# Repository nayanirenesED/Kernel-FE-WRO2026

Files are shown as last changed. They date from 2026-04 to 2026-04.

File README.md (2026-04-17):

# 🤖 KERNEL — WRO Future Engineers 2026

<p align="center">
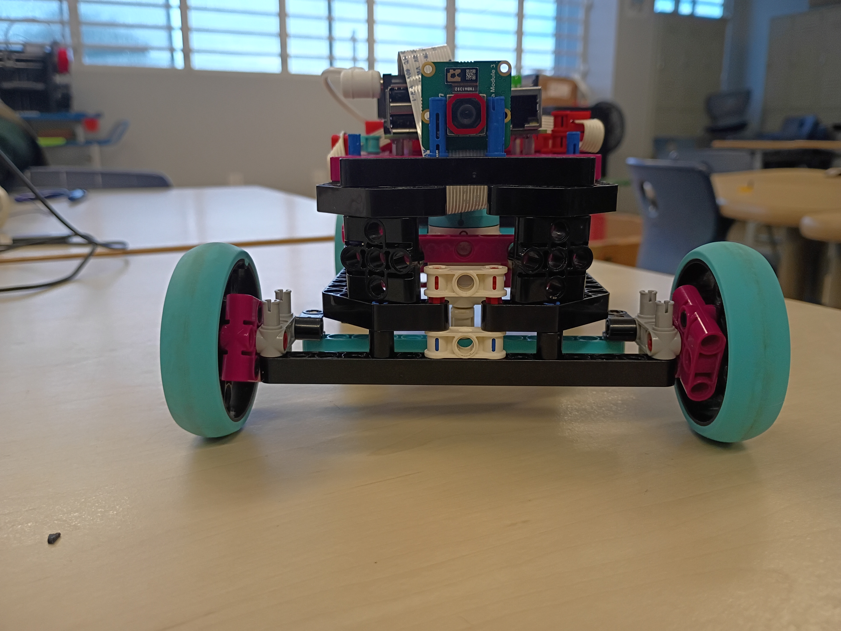
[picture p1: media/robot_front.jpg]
KERNEL Robot
  
</p>

> **World Robot Olympiad 2026 – Future Engineers**  
> Self-Driving Cars Challenge | Barceloneta, Puerto Rico 🇵🇷

---

## 👥 The Team

| Name | Role |
|---|---|
| Nayán G. Irenes Torres | Software Development |
| Yatziel O. Rivera Álvarez | Mechanical Design |
| Jesús Montoyo Heredia | Electronics & Sensors |
| Yanrick G. Irenes Torres | Media & Documentation |

**Coach:** Carlos Olivera  
**Location:** Barceloneta, Puerto Rico  
**Category:** WRO Future Engineers 2026 (Ages 14–22)

---

## 📋 Table of Contents

1. [What the Challenge Is About](#what-the-challenge-is-about)
2. [How We Think About It](#how-we-think-about-it)
3. [How the Robot Evolved](#how-the-robot-evolved)
4. [How the Robot Is Built (V2)](#how-the-robot-is-built-v2)
5. [Power System](#power-system)
6. [Sensors](#sensors)
7. [How the Software Works](#how-the-software-works)
8. [Decisions We Made and Why](#decisions-we-made-and-why)
9. [Repository Structure](#repository-structure)
10. [How to Reproduce Our Robot](#how-to-reproduce-our-robot)

---

## 🏁 What the Challenge Is About

The WRO Future Engineers 2026 challenge requires teams to build a fully autonomous vehicle that moves completely on its own, with no one controlling it. There are two rounds:

**Round 1:** The robot has to complete 3 full laps around a square track. At each corner, the robot has to decide whether to turn right or left on its own, without knowing in advance which direction it'll be running that round.

**Round 2:** Same as Round 1, but now there are obstacles on the track. Green obstacles have to be avoided on the left, red ones on the right. At the end, the robot has to reverse-park inside a zone marked in magenta.

The hardest part is that the track changes every round, and the robot never knows exactly what it'll find. It has to make its own decisions.

---

## 💡 How We Think About It

From the start, we asked ourselves: what's better, **a complicated robot or a robot that always works?**

We chose the second one. **Simple = Reliable.**

A robot with a lot of parts has a lot of things that can break. Code that's hard to read is hard to fix the night before a competition. We applied this thinking to every decision we made; fewer mechanical parts, modular code, well-placed sensors, and testing often to catch problems early.

---

## 🔄 How the Robot Evolved

We didn't get to V2 in a straight line. The robot went through a real evolution driven by what we learned at the first regional competition.

### Robot V1 — LEGO Only

Our first version used only LEGO SPIKE Prime components:

- SPIKE Prime Hub (main controller)
- Large Motor (traction)
- Medium Motor (steering)
- Color Sensor (floor line detection)
- **Official SPIKE Prime rechargeable battery** (plugs directly into the hub)

No Raspberry Pi, no camera, no external sensors. Simple, self-contained, and powered entirely by the LEGO hub battery.

The color sensor was the bottleneck. It needed to be very close to the floor to read reliably, so close that by the time it detected a line, the robot was almost past it. And without a camera, we had no way to detect obstacles at all.

### February 21, 2026 — First Regional Competition

We competed in the first regional with V1. We couldn't get consistent lap completions; the sensor limitations were obvious on the real track. But competing was worth it. We saw the actual track, the lighting, and what we were really up against.

After the regional, we made the call: rebuild.

### Robot V2 — The Hybrid (Current)

We kept what worked and replaced what didn't:

| | V1 | V2 |
|--|----|----|
| Controller | SPIKE Prime Hub | Raspberry Pi 4B + Build HAT |
| Line detection | SPIKE Color Sensor | Arducam IMX708 12MP camera |
| Distance sensing | None | 3× VL53L0X ToF sensors |
| Orientation | None | BNO08X IMU |
| Traction motor | LEGO Large ✅ kept | LEGO Large ✅ |
| Steering motor | LEGO Medium ✅ kept | LEGO Medium ✅ |
| Wheels | LEGO | LEGO (custom 3D-printed in progress) |
| **Power** | **SPIKE hub battery** | **18650 Li-ion cells + LX-2BUPS module** |

The motors stayed — they're precise and reliable. Everything else changed.

**The power problem** was one of the hardest challenges in the transition. V1 ran off the LEGO hub's built-in rechargeable battery. Plug it in, and it works. V2 is a completely different story. The Raspberry Pi and Build HAT need an external power source, and the Build HAT specifically requires 8–12V through a barrel jack.

Finding the right battery setup took a lot of time and research. This was one of the main reasons we couldn't participate in the second regional on March 28th; we hadn't fully validated the power system in time.

### March 28, 2026 — Second Regional

We weren't able to participate. Between the power system not being fully validated and the overall state of V2 at that point, we made the call to sit this one out and keep building.

---

## ⚙️ How the Robot Is Built (V2)

### The Chassis

Built on LEGO Technic pieces, lets us adjust quickly without special tools. Approximately **250 × 150 × 110 mm**, around **600 grams**, within WRO's size limits.

**Rear-wheel drive:** two driven wheels in the back, free-spinning wheels in front. Simple and light.

### The Motors

| Motor | Port | What It Does |
|---|---|---|
| SPIKE Prime Large Motor | Port A (Build HAT) | Moves the robot forward |
| SPIKE Prime Medium Motor | Port B (Build HAT) | Controls steering |

The steering motor uses absolute position control: 0° straight, +90° right, -90° left. Much more precise than time-based control, which varies with battery voltage.

### Physical Buttons

The robot has two physical buttons for competition use:

| Button | Color | Function |
|---|---|---|
| Power | 🔴 Red | Cuts power between LX-2BUPS and Build HAT |
| Run | 🟢 Green | Starts `kernel_robot_r1.py` via GPIO 17 |

The green button connects to **GPIO 17 (Pin 11)** and **GND (Pin 9)** on the Raspberry Pi. 
When pressed, it triggers `boton_inicio.py`, which launches the main robot program automatically.

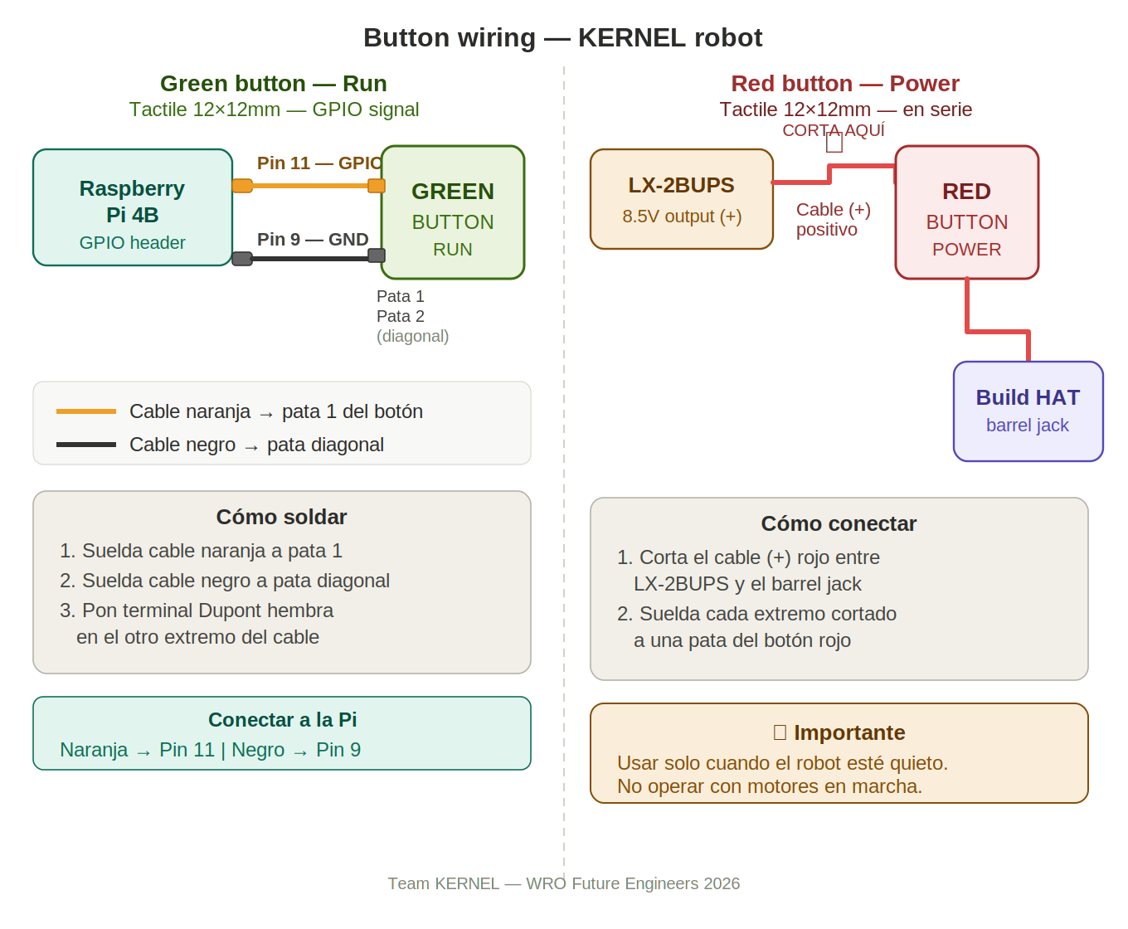
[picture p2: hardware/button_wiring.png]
Button wiring


### The Wheels

V2 currently runs on standard LEGO wheels. The custom wheel design is in progress:

- **Rim:** PLA/PETG, ~65mm diameter, 22mm wide, designed in CAD from scratch using Fusion 360
- **Tire:** TPU (or similar flexible filament) for better grip on the competition surface

<p align="center">
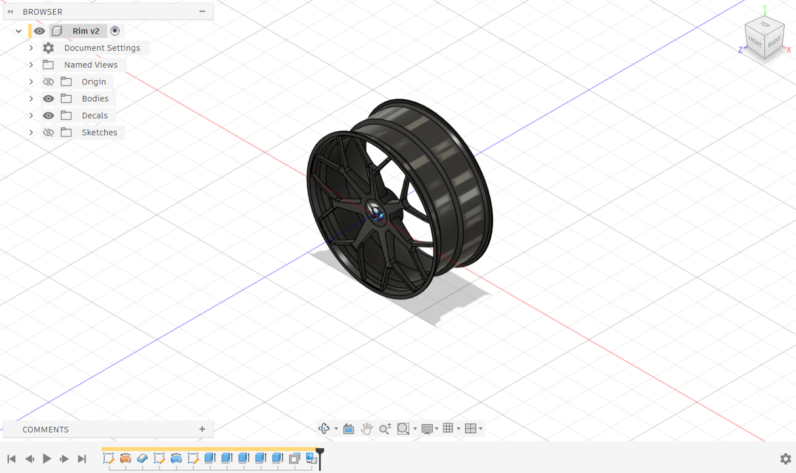
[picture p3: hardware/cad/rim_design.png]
Rim CAD design in Fusion 360
  
</p>

---

## 🔋 Power System

This was one of the biggest engineering challenges of the whole project.

### V1 Power: Simple

V1 used the **official SPIKE Prime rechargeable battery** that plugs directly into the hub. No external wiring, no voltage management, nothing to figure out. Just charge it and go.

### V2 Power: A Whole Different Problem

V2 needs to power two things simultaneously:
- The **Raspberry Pi 4B** needs stable 5V
- The **Build HAT** needs 8–12V through a barrel jack

After researching options and testing different setups, our solution is **two 18650 lithium cells** connected to an **LX-2BUPS boost module**. This module outputs a stable 8.5V to the Build HAT barrel jack. The Build HAT then passes power to the Raspberry Pi through its GPIO pins — one battery source for the entire robot.

| Component | Voltage | Approximate Current |
|---|---|---|
| Raspberry Pi 4B | 5V | ~1.5–2.5A |
| Build HAT + motors | 8.5V | up to 3A under load |
| IMX708 Camera | 3.3V | ~0.25A |
| 3× ToF sensors | 3.3V | ~0.06A total |
| BNO08X IMU | 3.3V | ~0.01A |

### The Battery Case

To keep the power system secure on the robot, we designed and printed a custom case that holds the LX-2BUPS module and the two 18650 cells together in one unit. Having the power system loose wasn't an option for competition.

<p align="center">
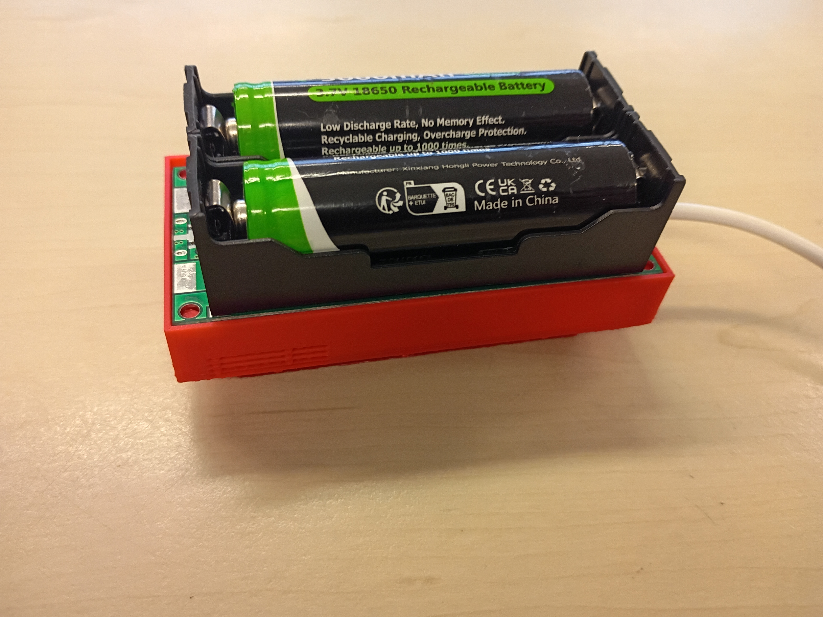
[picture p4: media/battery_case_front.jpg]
Custom battery case
  
</p>

### What We Know and What We're Still Testing

The 18650 cells have been tested, and the system works. One thing we're still validating is full endurance, how the cells perform through a complete competition run under full motor load. The cells must stay above 3.5V under load, or the Build HAT can reset. We'll find out definitively at the next regional.

We test the batteries before every session.

---

## 📡 Sensors

### Competition Setup (April 2026 Regional)

For this regional we made a deliberate decision: **run on camera only.** The Arducam IMX708 gives us everything we need to complete both rounds — line colors, obstacle colors, position, and distance. Fewer components means fewer things that can fail on competition day.

**Arducam IMX708 (12MP)** — the main and only active sensor. Connected via CSI cable, aimed forward and slightly down. Detects:
- Orange and blue floor lines → turn direction
- Red and green obstacles → bypass direction
- Position: left, center, right
- Distance: far, medium, close, very close

### Acquired and Tested (Future Integration)

We acquired, wired, and tested the following sensors on the bench. They work and will be integrated in a future version:

```
Raspberry Pi 4B
       │
  TCA9548A (I2C multiplexer)
  ├── Channel 0: VL53L0X ToF — Front
  ├── Channel 1: VL53L0X ToF — Left
  ├── Channel 2: VL53L0X ToF — Right
  └── Channel 3: BNO08X IMU
```

We confirmed that both the multiplexer (0x70) and IMU (0x4b) are detected on the I2C bus, and the IMU outputs quaternion data correctly.

| Sensor | Status | Purpose |
|---|---|---|
| IMX708 12MP camera | ✅ Active | Line detection, obstacle detection, navigation |
| VL53L0X ×3 | 🔜 Future | Precise distance to obstacles and walls |
| BNO08X IMU | 🔜 Future | Heading correction and orientation |
| SPIKE Color Sensor | V1 only | Used in V1, not present in V2 |

### Wiring Diagram

<p align="center">
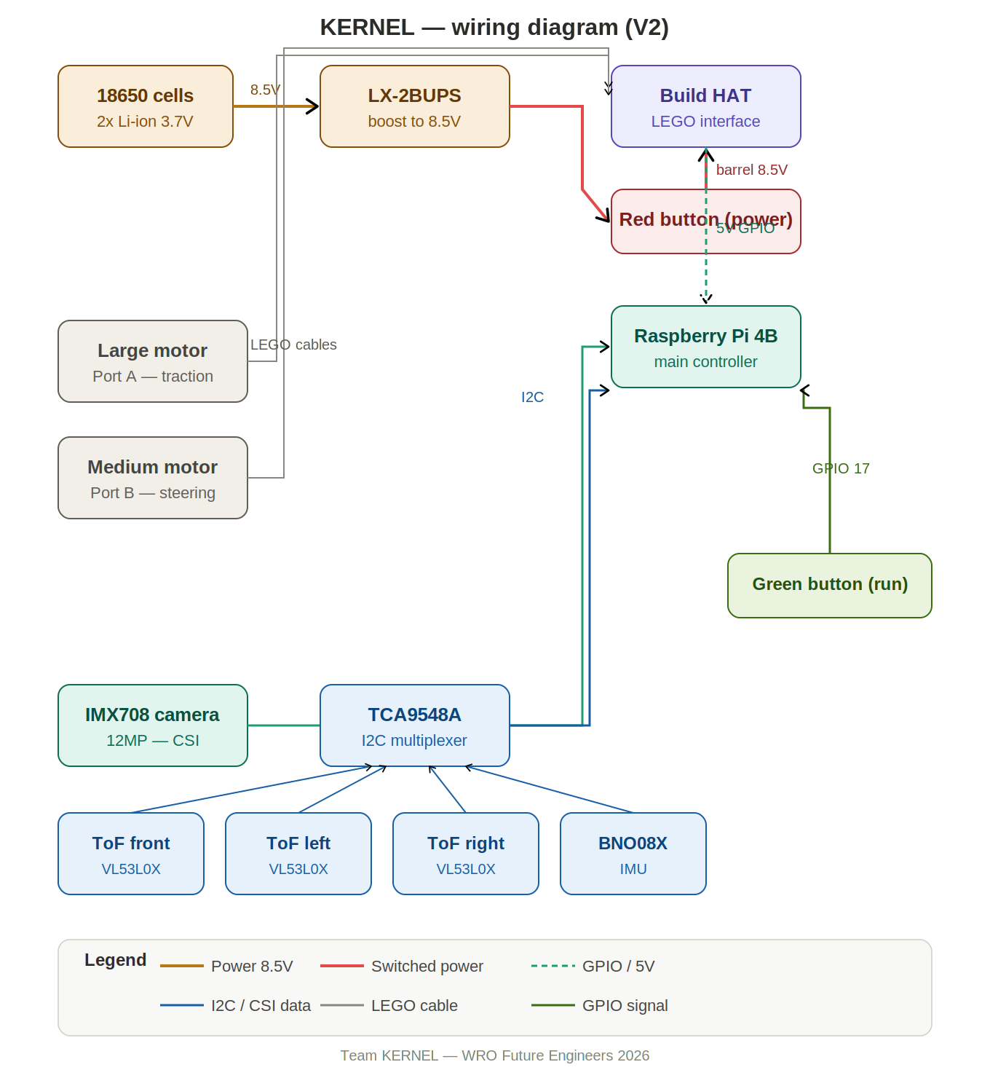
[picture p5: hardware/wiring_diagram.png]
Wiring Diagram
  
</p>

---

## 💻 How the Software Works

### One Program, Both Rounds

```
┌─────────────────────────────────────────────────────┐
│                  Raspberry Pi 4B                    │
│                                                     │
│  ┌─────────────────┐   JSON data    ┌─────────────┐ │
│  │  wro_camera.py  │ ─────────────▶ │kernel_robot │ │
│  │   (the "eyes")  │                │  _r1.py     │ │
│  │   Port 5000     │ ◀───────────── │(the "brain")│ │
│  └─────────────────┘                └─────────────┘ │
│         │                                 │         │
│    IMX708 Camera                     Build HAT       │
│                                      Motors A & B    │
└─────────────────────────────────────────────────────┘
```

- **`wro_camera.py`** — processes camera frames, detects colors, publishes JSON results on port 5000. Viewable live in any browser.
- **`kernel_robot_r1.py`** — handles **both Round 1 and Round 2** in a single program. Reads camera data every 50ms, decides what to do, and moves the motors. Round 1 logic (line following) and Round 2 logic (obstacle avoidance) are both in here.

### How It Decides at Each Corner

```
        Starts
           │
           ▼
    ┌─────────────┐
    │   Moving    │ ◀──────────────────────────┐
    │   forward   │                            │
    └──────┬──────┘                            │
           │                                   │
    Sees a colored line?                       │
           │                                   │
      ┌────┴────┐                              │
      ▼         ▼                              │
   Orange      Blue                            │
   → Turn      → Turn                          │
    right       left                           │
      └────┬────┘                              │
           ▼                                   │
    Wait 3 seconds ─────────────────────────── ┘
           │
    Reached 12 corners?
           │
           ▼
        Stop ✅  (3 laps done)
```

4 corners = 1 lap. 12 corners = 3 laps. The 3-second wait after each turn prevents the same line from being counted twice (entering and exiting the turn).

### Color Detection

HSV detection — more stable than RGB under changing lighting.

| Element | H Range | S Range | V Range |
|---|---|---|---|
| Orange line 🟠 | 8–22 | 150–255 | 100–255 |
| Blue line 🔵 | 100–130 | 150–255 | 50–255 |
| Red obstacle 🔴 | 0–10 / 170–179 | 150–255 | 80–255 |
| Green obstacle 🟢 | 45–80 | 150–255 | 50–255 |
| Parking zone 🟣 | 140–170 | 150–255 | 50–255 |

**Zone filter:** Detection of orange and blue is restricted to the bottom half of the frame. The cardboard walls that we used while testing are the same colors as the floor lines. Without this filter, the robot turned randomly every time it saw a wall.

### Code Structure

```
src/
├── kernel_robot_r1.py     # Main program
├── wro_camera.py          # Vision server
├── calibrar_colores.py    # Color calibration tool
├── sensors/
│   ├── tof.py
│   └── imu.py
└── actuators/
    └── motors.py
```

Camera server starts automatically on boot via systemd — no keyboard or screen needed.

---

## 🧠 Decisions We Made and Why

### Problems We Solved

| Problem | What Caused It | How We Fixed It |
|---|---|---|
| Motors didn't respond | `console=serial0,115200` in `cmdline.txt` blocked the serial port | Deleted that line |
| Camera didn't show up | CSI cable inserted backwards | Physical check every time we open the robot |
| Random turns in straight sections | Colored walls triggered line detector | Zone filter: bottom half of frame only |
| Counted corners twice | Same line detected entering and exiting | 3-second blocking window after every turn |
| Never detected anything | JSON key names didn't match between programs | Synced all names exactly |
| Couldn't find the right battery for V2 | Build HAT needs 8–12V barrel jack, no simple off-the-shelf solution | 18650 cells + LX-2BUPS module + custom printed case |

### Risks We're Managing

| Risk | How Likely | How Bad | How We Handle It |
|---|---|---|---|
| 18650 cells drop under full load | Medium | High — robot resets | Test before every session, spare cells ready |
| HSV ranges off at competition venue | Medium | High — robot can't navigate | `calibrar_colores.py` ready for on-site recalibration |
| Turn angle needs adjustment | Medium | Medium | Single variable `ANGULO_GIRO`, easy to tune |
| Camera cable disconnects | Low | High | Physically secured; systemd detects failure |

---

## 📁 Repository Structure

```
Kernel-FE-WRO2026/
├── README.md
├── LICENSE
├── .gitignore
├── src/
│   ├── kernel_robot_r1.py
│   ├── wro_camera.py
│   └── calibrar_colores.py
├── hardware/
│   ├── wiring_diagram.png
│   └── cad/
│       ├── rim.stl
│       └── battery_case.stl
├── docs/
│   └── engineering_journal.md
└── media/
    ├── robot_front.jpg
    ├── robot_rear.jpg
    ├── robot_side_left.jpg
    ├── robot_side_right.jpg
    ├── robot_top.jpg
    ├── robot_bottom.jpg
    ├── robot_v1_top.jpg
    ├── robot_v1_front.jpg
    ├── robot_v1_rear.jpg
    ├── robot_v1_left.jpg
    ├── robot_v1_right.jpg
    ├── robot_v1_bottom.jpg
    ├── battery_case_front.jpg
    ├── battery_case_side.jpg
    ├── battery_case_back.jpg
    ├── battery_case_usbc.jpg
    ├── battery_case_interior.jpg
    ├── test_color_detection.jpg
    ├── test_multiplexer_imu.jpg
    ├── test_i2cdetect.jpg
    ├── test_imu_output.jpg
    ├── test_network_config.jpg
    ├── test_bug_lap_counting.jpg
    └── design_sketch.jpg
```

---

## 🔧 How to Reproduce Our Robot

### What You'll Need

- Raspberry Pi 4B (2GB RAM minimum)
- LEGO SPIKE Prime Build HAT
- SPIKE Prime Large Motor
- SPIKE Prime Medium Motor
- SPIKE Prime Color Sensor
- Arducam IMX708 12MP Camera
- 3× VL53L0X Distance Sensors
- BNO08X IMU
- TCA9548A I2C Multiplexer
- LX-2BUPS Boost Module + 2× 18650 Li-ion batteries
- LEGO Technic pieces for the chassis
- STL files in `hardware/cad/` for the battery case and optional custom wheels

### Raspberry Pi Configuration

Add to **`/boot/firmware/config.txt`**:
```
dtoverlay=imx708
dtoverlay=disable-bt
enable_uart=1
```

Remove from **`/boot/firmware/cmdline.txt`** if present:
```
console=serial0,115200
```

```bash
sudo usermod -aG dialout wro_kernel
```

### Install the Software

```bash
sudo apt update
sudo apt install python3-opencv python3-picamera2 python3-flask python3-numpy

pip3 install buildhat --break-system-packages
pip3 install adafruit-circuitpython-vl53l0x --break-system-packages
pip3 install adafruit-circuitpython-bno08x --break-system-packages
```

### Running the Robot

```bash
# Terminal 1 — Vision server
python3 src/wro_camera.py

# Terminal 2 — Main logic
sudo -E python3 src/kernel_robot_r1.py
```

### Connecting to the Robot

| Method | Address |
|---|---|
| Ethernet direct | `192.168.10.1` |
| Robot WiFi | Network: `WRO-KERNEL` / Password: `wrokernel2025` |
| Live camera feed | `http://192.168.10.1:5000` in a browser |

---

## 📜 License

MIT — see [LICENSE](LICENSE).

---

*KERNEL — Representing Fernando Suria Chaves High School with hard work and heart. 🇵🇷*

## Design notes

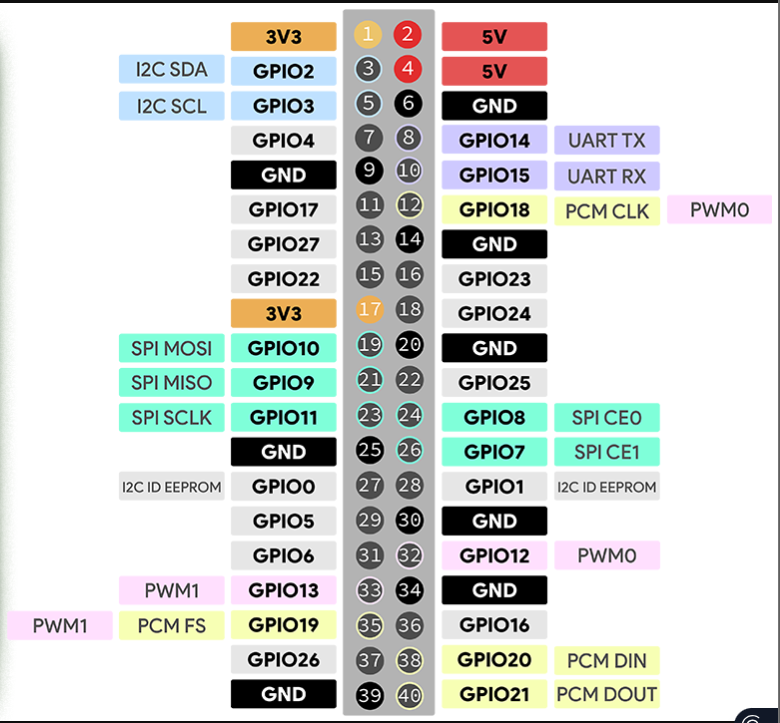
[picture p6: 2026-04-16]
hardware/raspberry_pi_gpio.jpg.png

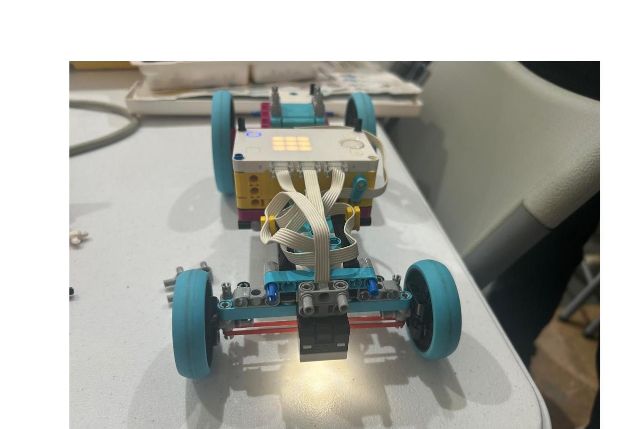
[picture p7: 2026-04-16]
media/robot_v1_front.jpg

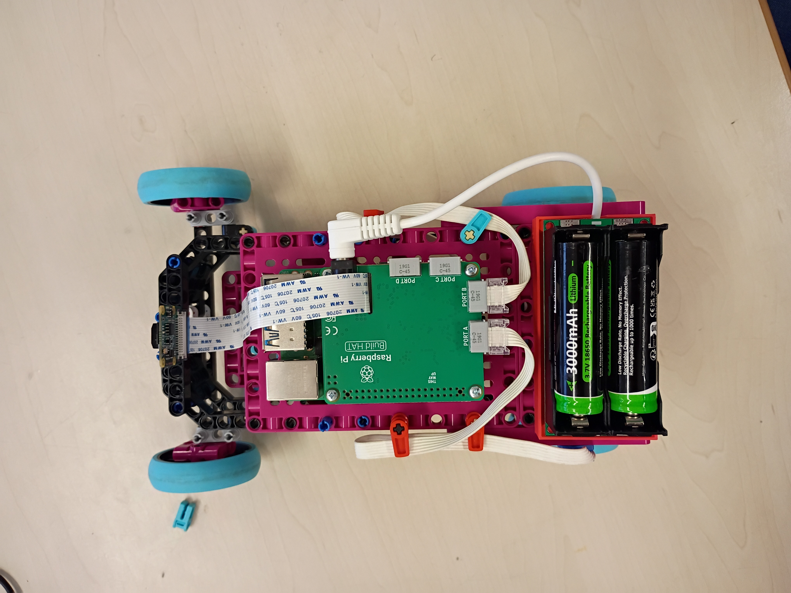
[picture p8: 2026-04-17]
media/robot_top.jpg

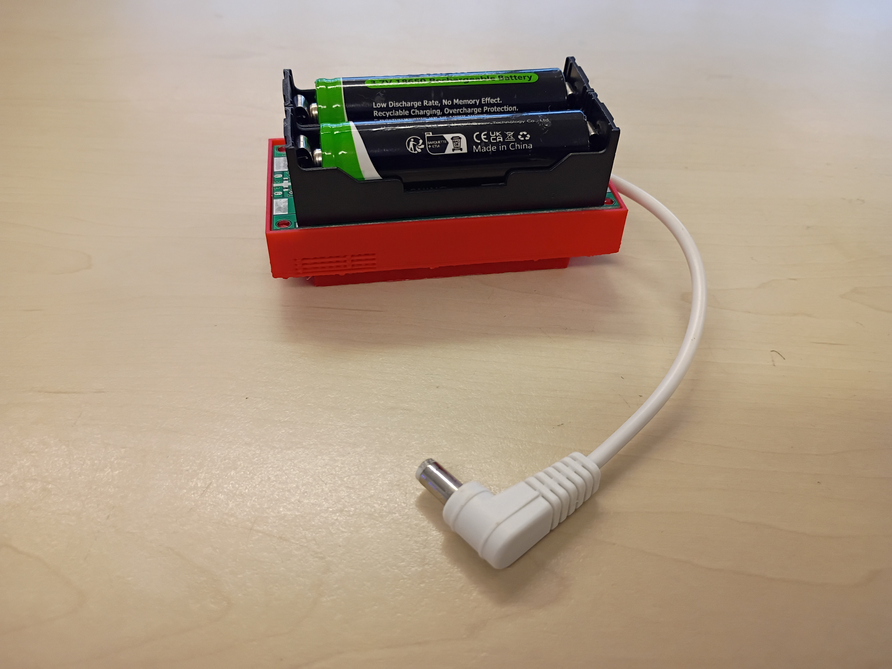
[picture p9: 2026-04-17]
media/battery_case_side.jpg

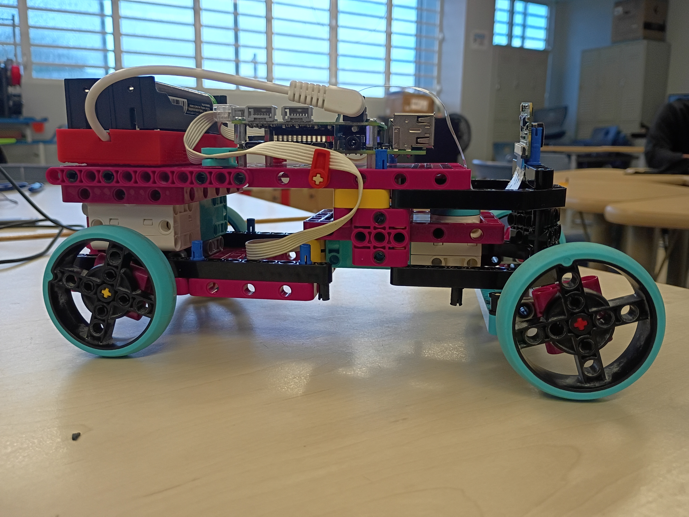
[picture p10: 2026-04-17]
media/robot_side_right.jpg

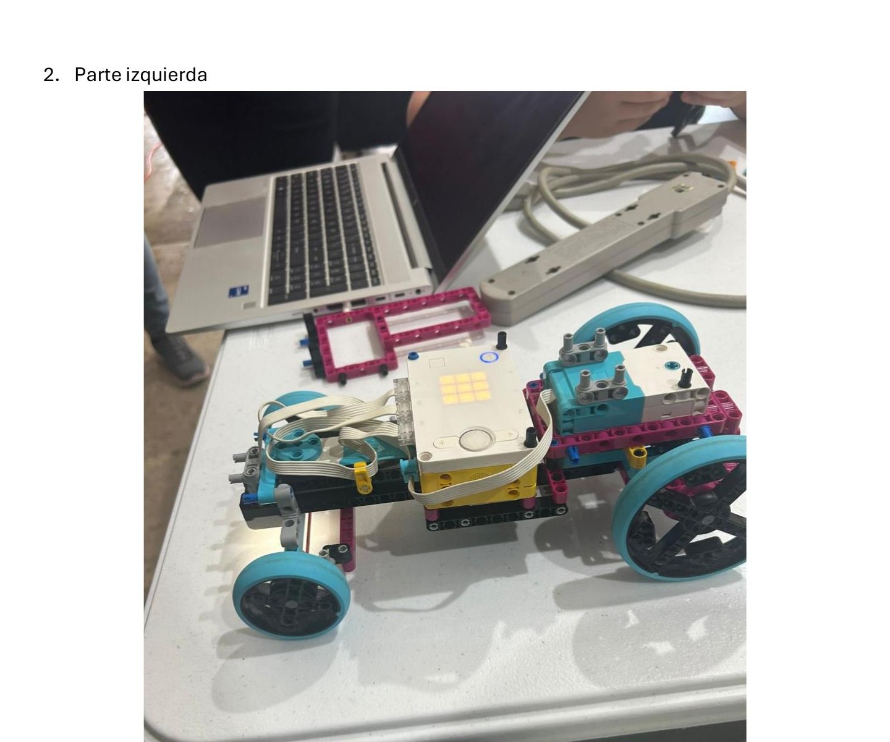
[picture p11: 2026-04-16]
media/robot_v1_left.jpg

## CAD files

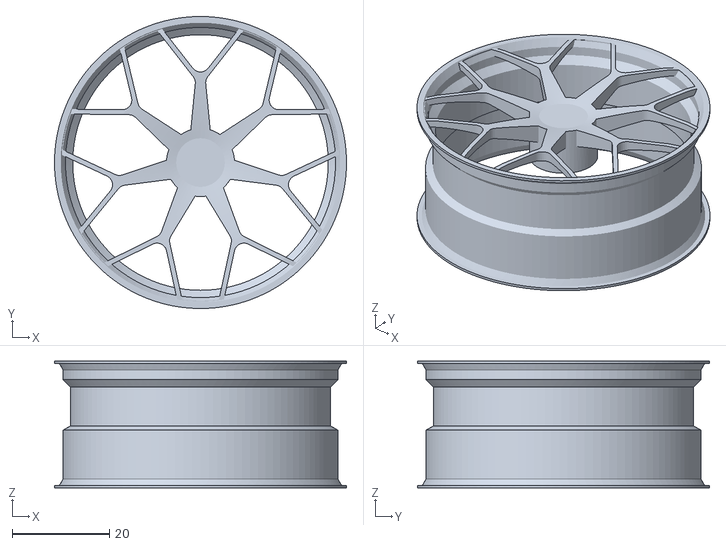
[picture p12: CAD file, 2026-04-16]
hardware/Kernel Rim v2.stl
60.0 x 60.0 x 26.0

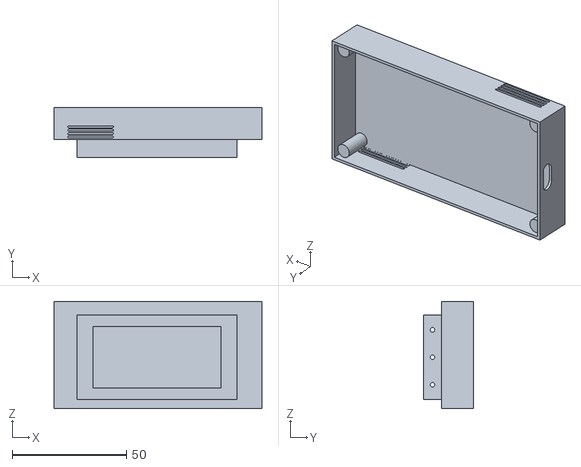
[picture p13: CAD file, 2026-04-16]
hardware/Battery box base test v2.stl
91.0 x 22.0 x 47.0

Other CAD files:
hardware/cad/Battery box base.f3d
hardware/cad/Kernel Rim.f3d

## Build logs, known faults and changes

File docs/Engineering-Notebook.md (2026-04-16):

# Engineering Journal — Team KERNEL
**WRO Future Engineers 2026 | Arecibo, Puerto Rico**

---

## January 20, 2026 — First Meeting

Today was our first official meeting as a team. The WRO Future Engineers challenge was launched on January 16th by TechnoInventor, so we spent the first few days reading through the rules and figuring out what we were actually getting ourselves into.

We have four people: Nayán, Yatziel, Yanrick, and Jesús. Our coach is Carlos Olivera. We split responsibilities based on what each of us is best at — Nayán is handling all the software and programming, Yatziel is on mechanical design, Jesús is taking care of electronics and sensors, and Yanrick is handling media and documentation.

We looked at the challenge requirements for Round 1 and Round 2 and started thinking about what hardware we'd need. We already had access to a LEGO SPIKE Prime set, so we decided to start there and see how far we could get.

Main goal from day one: keep it simple. We've seen teams over-engineer their robots and then spend competition day fixing things. We don't want that.

---

## Late January 2026 — Robot V1: LEGO Only

Our first version of the robot used only LEGO SPIKE Prime components:

- SPIKE Prime Hub (main controller)
- Large Motor (traction)
- Medium Motor (steering)
- Color Sensor (floor line detection)
- Official SPIKE Prime rechargeable battery (plugs directly into the hub)

The idea was to keep everything in one place. It drove, it could follow commands, and the color sensor could detect lines when it was close enough to the floor.

But "close enough" was the problem. The SPIKE Prime Color Sensor needs to be very close to the surface to read reliably — so close that by the time it detected a line, the robot was basically already past it. Response time was too slow for the speed we needed. And without a camera, we had no way to detect obstacles or plan any kind of path.

We knew going into the first regional that V1 had real limitations. We went anyway to learn.

---

## February 21, 2026 — First Regional Competition

We competed in the first regional with V1.

It was a tough day. The color sensor range issues we'd seen in practice were even more obvious on the actual competition track. We couldn't get consistent lap completions. The robot was functional but not competition-ready at the level we needed.

The experience was still worth it. We saw the real track setup and lighting conditions, and it completely confirmed what we already suspected: LEGO sensors alone were not going to work for this challenge. The sensor range just isn't there.

After the regional, we made the call — we were rebuilding.

---

## Late February 2026 — The Decision: Robot V2

After the first regional, we defined what V2 would look like. The goal was to keep what worked from V1 and replace everything that didn't.

**What we kept:**
- LEGO Large Motor (traction) — precise, reliable, no reason to replace it
- LEGO Medium Motor (steering) — same
- LEGO wheels — still using these for now

**What we added:**
- Raspberry Pi 4B as the main controller
- LEGO SPIKE Prime Build HAT to connect the Pi to the LEGO motors
- Arducam IMX708 12MP camera — this becomes the main sensor for everything
- 3× VL53L0X ToF distance sensors (acquired and tested, not used in competition yet)
- BNO08X IMU (acquired and tested, not used in competition yet)
- TCA9548A I2C multiplexer for the sensors
- LX-2BUPS boost module + 2× 18650 Li-ion batteries

**The power problem** hit us right away. V1 ran off the official SPIKE Prime hub battery. Simply plug it in, and it works. V2 is completely different. The Raspberry Pi and Build HAT need an external power source, and the Build HAT specifically requires 8–12V through a barrel jack.

Finding the right battery setup took significant time and research. This was one of the main reasons we couldn't participate in the second regional on March 28th — we hadn't fully validated the power system in time. We also designed and printed a custom case to hold the LX-2BUPS module and the 18650 cells securely on the chassis.

---

## March 28, 2026 — Second Regional (We Couldn't Participate)

The second regional was on March 28th. Between the power system not being fully validated and the overall state of V2, we made the decision not to compete. We used the time to keep building and get the system solid.

---

## Early March 2026 — Building V2: First Problems

We started assembling V2. The first big problem: the motors didn't respond at all.

The Build HAT library wasn't throwing errors; it just wasn't communicating. After a lot of searching, we found the issue: a line in the Raspberry Pi boot file (`cmdline.txt`) called `console=serial0,115200` makes the OS claim the serial port before the Build HAT can use it. Delete it, add `dtoverlay=disable-bt` and `enable_uart=1` to the other config file — and it works.

No error message, no warning. Just silence. Finding this took way longer than it should have.

---

## Mid March 2026 — Camera Setup

We connected the Arducam IMX708 via CSI ribbon cable. First attempt: nothing.

The ribbon cable was inserted backwards. The IMX708 cable has a specific orientation; flip it, and the camera doesn't initialize with no error explaining why. Physical check fixed it.

After adding `dtoverlay=imx708` to the config file, the camera worked. We set up `wro_camera.py` — a Flask server that processes frames and detects colors using HSV. It streams live to any browser on the network at port 5000, and shows detections with position (left, center, right) and distance (far, medium, close, very close) in real time.

---

## Late March / Early April 2026 — Color Detection and Testing

We built `calibrar_colores.py` — interactive HSV sliders to tune color ranges in real time.

We also used the official color values in the WRO 2026 rulebook (pages 26–28):

| Element | Official Color | Notes |
|---|---|---|
| Orange line | CMYK(0, 60, 100, 0) | ~RGB(255, 102, 0) |
| Blue line | CMYK(100, 80, 0, 0) | ~RGB(0, 51, 255) |
| Red obstacle | RGB(238, 39, 55) | |
| Green obstacle | RGB(68, 214, 44) | |
| Magenta parking | RGB(255, 0, 255) | Pure magenta |

Having the exact official colors made calibration much more accurate than guessing.

**Zone filter:** We restricted orange and blue line detection to only the bottom half of the camera frame. The cardboard walls on the practice track are also detected as orange and red without this filter; the robot turned randomly whenever it saw a wall. One of the most important fixes in the whole project.

**Silent bug we hit:** The vision server sent data as `"linea_naranja"`, but the robot code looked for `"naranja"`. Wrong key name, complete failure, no error messages. We now double-check every key name any time detection stops working.

**Double-counting fix:** Without a 3-second blocking window after each turn, the robot detected the same corner line twice and counted it twice. We spent a while figuring out why it was finishing "6 laps" when it had only done 3.

---

## Mid March 2026 — Sensor Testing (ToF and IMU)

Even though we're not using the ToF sensors or IMU in competition yet, we tested them to confirm they work and understand how to integrate them later.

We set up the TCA9548A multiplexer on a breadboard with the BNO08X IMU and connected it to the Raspberry Pi. Using `i2cdetect -y 1`, we confirmed both devices were visible on the I2C bus — the multiplexer at address `0x70` and the IMU at `0x4b`.

We then ran `test_imu.py` and got quaternion data streaming in real time — the IMU initialized correctly and was reading orientation continuously.

The ToF sensors and IMU are ready to be integrated into the main program in a future version. For this regional we're keeping things simple and running on camera only.

---

## April 2026 — Competition Strategy Decision

**Camera-only approach for the third regional.**

After evaluating the time we have left before the April 19th competition and the current state of the robot, we made a deliberate decision: run this regional using only the camera, without the ToF sensors or IMU.

The reasons:

1. The camera already detects everything we need — line colors, obstacle colors, positions, and distances
2. Fewer components = fewer things that can fail on competition day
3. The ToF and IMU work but haven't been integrated and tested in the full robot loop yet
4. Two days is not enough time to safely integrate, test, and validate new sensors before a competition

The camera gives us:
- Orange/blue line detection → turn direction for Round 1
- Red/green obstacle detection → bypass direction for Round 2
- Position (left, center, right) → where the obstacle is
- Distance (far, medium, close, very close) → when to start the maneuver

That's everything we need to run both rounds.

**Single program for both rounds.**

We also decided to keep everything in one program — `kernel_robot_r1.py` — rather than splitting Round 1 and Round 2 into separate files. The same program handles both: it completes 3 laps reading orange/blue lines, and during those laps, it also reacts to red and green obstacles. One program, less complexity, easier to debug on competition day.

The obstacle avoidance logic:
```
If camera sees red obstacle → steer right to bypass
If camera sees green obstacle → steer left to bypass
Trigger when distance = "close" or "very close"
After bypass → return to center and continue
```

---

## Current State — Before April 19 Regional

**Working:**
- Orange/blue line detection and automatic turn direction ✅
- Post-turn blocking window (3 seconds) ✅
- Corner and lap counting (12 corners = 3 laps) ✅
- Camera autostart on boot via systemd ✅
- Access via ethernet/laptop ✅
- Power system with 18650 cells + LX-2BUPS ✅
- Custom battery/UPS case designed and printed ✅
- Red/green obstacle detection with position and distance ✅

**In progress before Saturday:**
- Obstacle avoidance maneuver logic (steering around obstacles)
- Full Round 1 + Round 2 combined test run
- HSV calibration with official competition colors
- Battery endurance validation

**Planned for future versions:**
- Integrate ToF sensors for more precise distance measurement
- Integrate IMU for heading correction
- Separate Round 1 and Round 2 into cleaner code modules
- Custom 3D-printed wheels (designing in progress)

---

## Reflections So Far

The biggest lesson from this project isn't technical. It's that you have to be willing to start over when something isn't working. We built a full robot, competed with it, and rebuilt it from scratch because we knew it wasn't going to get us where we needed to be.

The power system challenge was one of the hardest non-code problems we faced. Going from a plug-in LEGO battery to a custom setup with boost modules and 18650 cells is a big jump — it slowed us down and cost us the second regional. But now we understand every part of our power system, and we have built a case for it.

The camera-only decision for this regional is also an engineering choice we're proud of. It would be easy to throw every sensor at the problem and hope it works. Instead, we asked: what do we actually need to complete the challenge? And the answer was simpler than we expected.

---

## April 16, 2026 — Power Cable Failure

During testing today, the positive power cable connecting the LX-2BUPS to the Build HAT broke. We need to repair or replace it before Saturday's competition. This is exactly the kind of failure point we identified in our risk analysis: Physical connections under repeated stress can fail. We're resoldering the cable today.

---

*Journal maintained by Team KERNEL — Barceloneta, Puerto Rico 🇵🇷*

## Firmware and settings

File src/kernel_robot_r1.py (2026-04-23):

#!/usr/bin/env python3
"""
Team KERNEL — WRO Future Engineers 2026
kernel_robot_r1.py — Main program (Round 1 and Round 2)

Round 1: 3 autonomous laps detecting orange/blue floor lines
Round 2: same logic + red/green obstacle avoidance + reverse parallel parking
Camera only — ToF and IMU waiting for testing
"""

import requests
import time
from buildhat import Motor

# ── CONFIGURATION ─────────────────────────────────────────────────────────────
VISION_URL      = "http://localhost:5000/detections"
MOTOR_TRACTION  = 'A'       # Large motor — Port A
MOTOR_STEERING  = 'B'       # Medium motor — Port B

SPEED           = 40       # Traction speed % (negative = forward)
TURN_ANGLE      = 90        # Degrees to turn at each corner
CENTER_ANGLE    = 0         # Steering motor center position
LAPS_TARGET     = 3         # Number of laps to complete

TURN_BLOCK      = 3.0       # Seconds to ignore detections after each turn

# Parking parameters
PARK_SPEED      = -20       # Slower speed for parking maneuver
PARK_REVERSE    = 30        # Reverse speed for parking (positive = backward)

# ── MOTORS ────────────────────────────────────────────────────────────────────
traction  = Motor(MOTOR_TRACTION)
steering  = Motor(MOTOR_STEERING)

# ── MOVEMENT FUNCTIONS ────────────────────────────────────────────────────────

def get_detections():
    """Fetch current detections from the vision server (Flask)."""
    try:
        r = requests.get(VISION_URL, timeout=0.3)
        return r.json()
    except:
        return {}

def line_detected(detections, color):
    """Return True if the given color line is detected."""
    return color in detections and len(detections[color]) > 0

def obstacle_detected(detections, color):
    """Return True if an obstacle of the given color is detected."""
    return color in detections and len(detections[color]) > 0

def parking_detected(detections):
    """Return True if the magenta parking zone is detected."""
    return "estacionamiento_magenta" in detections and len(detections["estacionamiento_magenta"]) > 0

def center_steering():
    """Return steering motor to center position."""
    steering.run_to_position(CENTER_ANGLE, speed=50)

def turn_right():
    print("[TURN] Right >>>")
    steering.run_to_position(TURN_ANGLE, speed=50)

def turn_left():
    print("[TURN] Left <<<")
    steering.run_to_position(-TURN_ANGLE, speed=50)

def avoid_right():
    """Bypass a red obstacle on the right side."""
    print("[OBSTACLE] Red → bypassing right")
    steering.run_to_position(TURN_ANGLE, speed=40)
    time.sleep(1.0)
    center_steering()
    time.sleep(0.5)
    steering.run_to_position(-TURN_ANGLE, speed=40)
    time.sleep(1.0)
    center_steering()

def avoid_left():
    """Bypass a green obstacle on the left side."""
    print("[OBSTACLE] Green → bypassing left")
    steering.run_to_position(-TURN_ANGLE, speed=40)
    time.sleep(1.0)
    center_steering()
    time.sleep(0.5)
    steering.run_to_position(TURN_ANGLE, speed=40)
    time.sleep(1.0)
    center_steering()

def move_forward():
    traction.start(SPEED)

def move_slow():
    """Move forward slowly for parking approach."""
    traction.start(PARK_SPEED)

def stop():
    traction.stop()
    center_steering()
    print("[STOP] Robot stopped")

# ── PARKING MANEUVER ──────────────────────────────────────────────────────────

def reverse_parallel_park():
    """
    Reverse parallel parking maneuver.
    The parking zone is identified by two magenta walls.
    Strategy:
      1. Move forward past the parking zone entry
      2. Steer right and reverse into the zone
      3. Straighten and stop inside the zone
    """
    print("[PARKING] Magenta zone detected — starting reverse parallel park")

    stop()
    time.sleep(0.5)

    # Step 1: Move forward slightly to align with parking zone
    move_slow()
    time.sleep(0.8)
    stop()
    time.sleep(0.3)

    # Step 2: Steer right and reverse into the parking zone
    steering.run_to_position(TURN_ANGLE, speed=30)
    traction.start(PARK_REVERSE)
    time.sleep(1.2)

    # Step 3: Straighten steering while continuing to reverse
    center_steering()
    time.sleep(0.8)

    # Step 4: Stop inside the parking zone
    stop()
    print("[PARKING] Reverse parallel park complete")

# ── MAIN LOGIC ────────────────────────────────────────────────────────────────

def main():
    corners  = 0
    laps     = 0
    blocked  = False
    t_block  = 0
    parked   = False

    print(f"[KERNEL] Starting — Target: {LAPS_TARGET} laps")
    print("[KERNEL] Press Ctrl+C to stop\n")

    center_steering()
    time.sleep(0.5)
    move_forward()

    try:
        while laps < LAPS_TARGET or not parked:
            now = time.time()

            # Lift block if enough time has passed since last turn
            if blocked and (now - t_block) >= TURN_BLOCK:
                blocked = False
                center_steering()
                print("[OK] Ready for next corner")

            if not blocked:
                detections = get_detections()

                # ── After completing all laps: look for parking zone ──
                if laps >= LAPS_TARGET and not parked:
                    if parking_detected(detections):
                        reverse_parallel_park()
                        parked = True
                        break
                    # Keep moving slowly while searching for parking zone
                    move_slow()
                    time.sleep(0.05)
                    continue

                # ── Obstacle detection (Round 2) ──
                if obstacle_detected(detections, "obstaculo_rojo"):
                    avoid_right()

                elif obstacle_detected(detections, "obstaculo_verde"):
                    avoid_left()

                # ── Corner line detection (Round 1 and 2) ──
                elif line_detected(detections, "linea_naranja"):
                    print(f"[LINE] Orange → Right | Corner #{corners + 1}")
                    turn_right()
                    corners += 1
                    blocked  = True
                    t_block  = now

                elif line_detected(detections, "linea_azul"):
                    print(f"[LINE] Blue → Left | Corner #{corners + 1}")
                    turn_left()
                    corners += 1
                    blocked  = True
                    t_block  = now

                # ── Lap counting ──
                if corners > 0 and corners % 4 == 0 and not blocked and laps < corners // 4:
                    laps += 1
                    print(f"\n[LAP] Lap {laps}/{LAPS_TARGET} complete!\n")

            time.sleep(0.05)  # ~20Hz loop

    except KeyboardInterrupt:
        print("\n[KERNEL] Stopped by user")

    finally:
        stop()
        print(f"[KERNEL] Result: {laps}/{LAPS_TARGET} laps | {corners} corners | Parked: {parked}")

if __name__ == "__main__":
    main()

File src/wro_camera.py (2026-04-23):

#!/usr/bin/env python3
"""
Team KERNEL — WRO Future Engineers 2026
wro_camera.py — Vision server (Flask + HSV color detection)

Detects colors from the camera and publishes results as JSON at:
  GET http://localhost:5000/detections
  GET http://localhost:5000/video_feed  (live stream)

Official WRO 2026 colors (from rulebook pages 26-28):
  Orange line:    CMYK(0, 60, 100, 0)  ~ RGB(255, 102, 0)
  Blue line:      CMYK(100, 80, 0, 0)  ~ RGB(0, 51, 255)
  Red obstacle:   RGB(238, 39, 55)
  Green obstacle: RGB(68, 214, 44)
  Magenta parking: RGB(255, 0, 255)
"""

from flask import Flask, Response, render_template_string, jsonify
from picamera2 import Picamera2
import cv2
import numpy as np
import threading

app = Flask(__name__)
picam2 = Picamera2()
picam2.configure(picam2.create_preview_configuration(main={"size": (1280, 720)}))
picam2.start()

lock = threading.Lock()
output_frame = None
detection_data = {}

FRAME_W = 1280
FRAME_H = 720

# === CALIBRATED HSV RANGES FOR WRO — KERNEL ===
WRO_COLORS = {
    "obstaculo_rojo": {
        "ranges": [
            ([0,   150, 80],  [10,  255, 255]),   # Red wraps around 0/179 in HSV
            ([170, 150, 80],  [179, 255, 255])
        ],
        "draw_color": (0, 0, 255),
        "min_area": 1500
    },
    "obstaculo_verde": {
        "ranges": [([45, 150, 50], [80, 255, 255])],
        "draw_color": (0, 255, 0),
        "min_area": 1500
    },
    "linea_naranja": {
        "ranges": [([8, 150, 100], [22, 255, 255])],
        "draw_color": (0, 165, 255),
        "min_area": 800
    },
    "linea_azul": {
        "ranges": [([100, 150, 50], [130, 255, 255])],
        "draw_color": (255, 100, 0),
        "min_area": 800
    },
    "pared_negra": {
        "ranges": [([0, 0, 0], [179, 80, 35])],
        "draw_color": (128, 128, 128),
        "min_area": 3000
    },
    "estacionamiento_magenta": {
        "ranges": [([140, 150, 50], [170, 255, 255])],
        "draw_color": (255, 0, 255),
        "min_area": 1000
    },
}

def get_distance(area):
    """Estimate distance to detected object based on contour area."""
    if area > 50000:
        return "very_close"
    elif area > 20000:
        return "close"
    elif area > 8000:
        return "medium"
    return "far"

def get_position(cx):
    """Return horizontal position of detected object (left/center/right)."""
    if cx < FRAME_W // 3:
        return "left"
    elif cx < 2 * FRAME_W // 3:
        return "center"
    return "right"

def process_frame(frame_bgr):
    """
    Process a camera frame and detect all WRO colors.
    Applies zone filter: orange and blue lines are only detected
    in the bottom half of the frame to avoid false detections from walls.
    """
    hsv = cv2.cvtColor(frame_bgr, cv2.COLOR_BGR2HSV)
    detections = {}

    # Draw zone dividers (left / center / right)
    zone_w = FRAME_W // 3
    cv2.line(frame_bgr, (zone_w, 0), (zone_w, FRAME_H), (50, 50, 50), 1)
    cv2.line(frame_bgr, (2*zone_w, 0), (2*zone_w, FRAME_H), (50, 50, 50), 1)
    cv2.putText(frame_bgr, "LEFT",   (10, 20),           cv2.FONT_HERSHEY_SIMPLEX, 0.5, (200, 200, 200), 1)
    cv2.putText(frame_bgr, "CENTER", (zone_w+10, 20),    cv2.FONT_HERSHEY_SIMPLEX, 0.5, (200, 200, 200), 1)
    cv2.putText(frame_bgr, "RIGHT",  (2*zone_w+10, 20),  cv2.FONT_HERSHEY_SIMPLEX, 0.5, (200, 200, 200), 1)

    for name, config in WRO_COLORS.items():
        mask = np.zeros((FRAME_H, FRAME_W), dtype=np.uint8)
        for (lower, upper) in config["ranges"]:
            m = cv2.inRange(hsv, np.array(lower), np.array(upper))
            mask = cv2.add(mask, m)

        contours, _ = cv2.findContours(mask, cv2.RETR_EXTERNAL, cv2.CHAIN_APPROX_SIMPLE)
        detections[name] = []

        for cnt in contours:
            area = cv2.contourArea(cnt)
            if area > config["min_area"]:
                x, y, w, h = cv2.boundingRect(cnt)
                cy_cnt = y + h // 2

                # ZONE FILTER: orange and blue lines only in bottom half of frame
                # This prevents colored walls from triggering false line detections
                if name in ["linea_naranja", "linea_azul"] and cy_cnt < FRAME_H // 2:
                    continue

                cx = x + w // 2
                pos  = get_position(cx)
                dist = get_distance(area)

                detections[name].append({
                    "cx":       cx,
                    "cy":       cy_cnt,
                    "area":     int(area),
                    "pos":      pos,
                    "distancia": dist
                })

                # Draw bounding box and label on frame
                color = config["draw_color"]
                cv2.rectangle(frame_bgr, (x, y), (x+w, y+h), color, 2)
                cv2.circle(frame_bgr, (cx, cy_cnt), 4, color, -1)
                label = f"{name} | {pos} | {dist}"
                cv2.putText(frame_bgr, label, (x, y-8),
                            cv2.FONT_HERSHEY_SIMPLEX, 0.45, color, 1)

    # Active detections panel (top right)
    y_text = 40
    cv2.putText(frame_bgr, "Active detections:", (FRAME_W-250, y_text),
                cv2.FONT_HERSHEY_SIMPLEX, 0.45, (255, 255, 255), 1)
    for name, dets in detections.items():
        if dets:
            y_text += 18
            cv2.putText(frame_bgr, name, (FRAME_W-250, y_text),
                        cv2.FONT_HERSHEY_SIMPLEX, 0.4,
                        WRO_COLORS[name]["draw_color"], 1)
            for d in dets:
                y_text += 14
                cv2.putText(frame_bgr, f"  pos:{d['pos']} dist:{d['distancia']}",
                            (FRAME_W-250, y_text),
                            cv2.FONT_HERSHEY_SIMPLEX, 0.35, (200, 200, 200), 1)

    return frame_bgr, detections

def capture_frames():
    """Continuously capture frames from the camera and process them."""
    global output_frame, detection_data
    while True:
        frame = picam2.capture_array()
        frame_bgr = cv2.cvtColor(frame, cv2.COLOR_RGB2BGR)
        processed, detections = process_frame(frame_bgr)
        with lock:
            output_frame  = processed.copy()
            detection_data = detections

def generate():
    """Generate MJPEG stream for the live video feed."""
    global output_frame
    while True:
        with lock:
            if output_frame is None:
                continue
            _, encoded = cv2.imencode('.jpg', output_frame,
                                      [cv2.IMWRITE_JPEG_QUALITY, 70])
            frame_bytes = encoded.tobytes()
        yield (b'--frame\r\n'
               b'Content-Type: image/jpeg\r\n\r\n' + frame_bytes + b'\r\n')
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

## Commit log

2026-04-16 Update README.md
    Major README update: complete technical documentation, V1→V2 evolution, camera-only strategy, physical buttons, sensor testing evidence, and competition-ready content.
2026-04-16 Delete src/sensors.py
    Remove placeholder empty files
2026-04-16 Delete hardware/wiring-diagram
    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
2026-04-16 Add files via upload
    Add main robot programs: kernel_robot_r1.py (Round 1 & 2 logic), wro_camera.py (HSV vision server), calibrar_colores.py (calibration tool)
2026-04-16 Update Engineering-Notebook.md
    Add cable failure entry to engineering journal (April 16)
2026-04-17 Add files via upload
    Add V2 robot photos and battery case photos to media/
2026-04-17 Add files via upload
    Add rim CAD design screenshot from Fusion 360
2026-04-17 Update README.md
    Update README: add rim CAD image, fix battery case image reference, update repository structure with all media files
2026-04-17 Delete hardware/wiring-diagram
    Deleting empty file
